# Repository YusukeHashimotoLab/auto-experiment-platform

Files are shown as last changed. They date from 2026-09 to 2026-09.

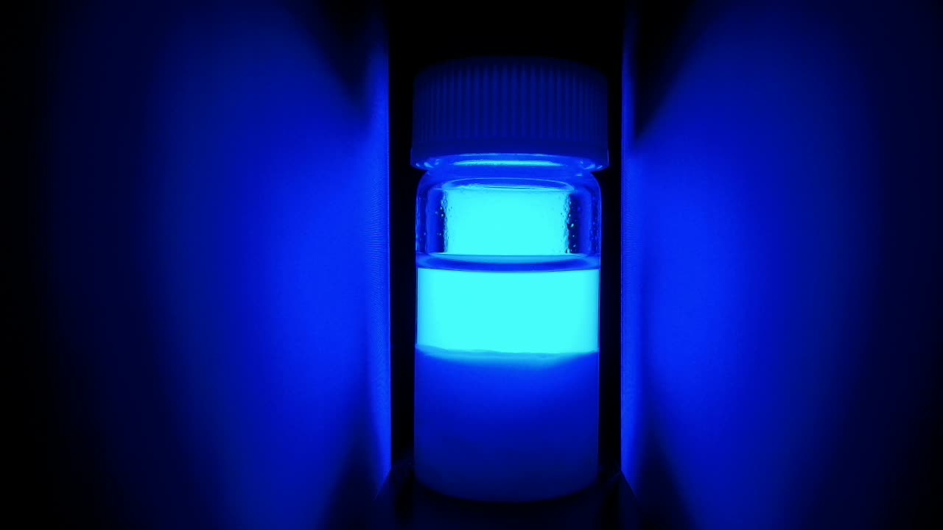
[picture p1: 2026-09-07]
src/imaging/examples/zif8_vial_5s/shot_blue.jpg

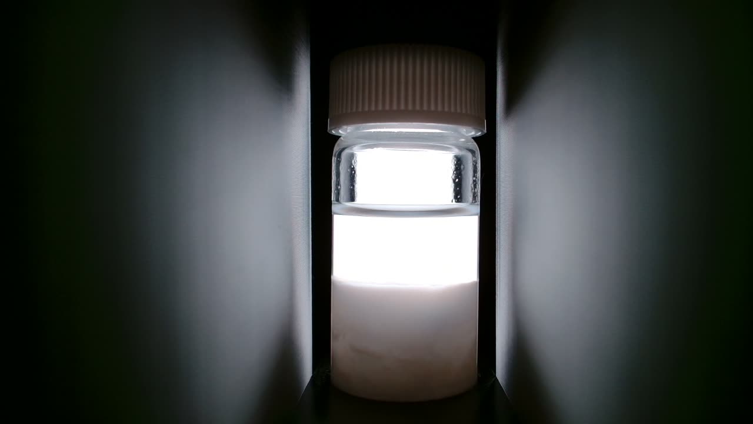
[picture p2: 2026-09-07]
src/imaging/examples/zif8_vial_5s/ref_white.jpg

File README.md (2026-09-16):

# SAIGEN

**SAIGEN** — **S**tandardized **A**utomation **I**nfrastructure for **G**eneralizable
**E**xperiment reproductio**N** (also *saigen*, 再現, Japanese for "reproduction").

A simple, easy-to-introduce, open-source platform for automated materials-synthesis
experiments, focusing on **reliable automation and quantitative process recording**
rather than full autonomy.

Repository: https://github.com/YusukeHashimotoLab/saigen

A manuscript describing the platform and its ZIF-8 demonstration is in preparation
(working title: *Quantitative control and improved reproducibility of materials
synthesis processes using an automated experimentation platform*). It is referred to
as "the paper" throughout this repository; a citation will be added here once it is
available.
<!-- TODO: add the citation / DOI when the manuscript is published, and add a
     preferred-citation block to CITATION.cff. -->

The platform combines commercially available instruments (robot arms, electric
pipettes, web cameras, an electronic balance) with 3D-printed fixtures, and operates
them with control code generated by an AI agent based on a large language model (LLM).
As a demonstration, ZIF-8 (a metal–organic framework) was synthesized with a
two-solution mixing system, and the dependence of its particle size distribution on
the solution dispensing speed was quantified and reproduced.

**Video:** the two-solution mixing system built on this platform, in operation:
https://youtu.be/5X2-4LuQfns

## Repository layout

| Path | Contents |
|---|---|
| `src/agent/` | AI agent that generates JSON experimental flows from natural language (Gemini API or any OpenAI-compatible endpoint) and the preset flows |
| `src/devices/` | Control drivers for each instrument (robot arm, electric pipette, hot-plate stirrer, electronic balance, webcam) and the safety wrapper the flows run through |
| `src/flow/` | Schema, validator, executor and command-line runner for the JSON experimental flow format |
| `src/gui/` | Browser-based GUI for parameter input and flow confirmation |
| `src/voice/` | Voice input (whisper-large-v3-turbo) |
| `src/monitoring/` | IoT sensor logging (Raspberry Pi + Environment Sensor HAT) and process cameras |
| `src/imaging/` | Appearance-imaging system: NEEWER RGB62 light + Logitech C920n camera control, white/red/green/blue capture sequence, cropped-image comparison and depth-direction transmitted-light profiles (paper Figure 6) |
| `detection/` | Object detection based on YOLOv8 — **kept separate for licensing reasons, see below** |
| `cad/` | CAD design bank of 3D-printable experimental components (STL + editable Fusion 360 sources) |
| `docs/` | Bill of materials, setup guide, experimental-flow format reference, spreadsheet-input guide, guide to adding an instrument |
| `examples/zif8/` | Sample experimental flows of the ZIF-8 demonstration (JSON equivalents of the spreadsheet sequence) and monitoring CSV templates |
| `examples/dispensing_stability/` | Measured data of the 100-shot dispensing-repeatability test and the script that recorded it |

## Getting started

1. See [`docs/bom.md`](docs/bom.md) for the full list of hardware used.
2. Print the fixtures in `cad/` (STL files; the Fusion 360 sources are included for
   modification — see [`cad/README.md`](cad/README.md)).
3. Follow [`docs/setup.md`](docs/setup.md) to connect the instruments to the control PC.
4. Copy `config.example.yaml` to `config.yaml` and set the COM ports and workspace
   limits of your own cell; copy `.env.example` to `.env` and set your API keys.
   **Never commit `.env` or `config.yaml`.**
5. Install the Python dependencies: `pip install -r requirements.txt`
   (module-specific notes, e.g. for the imaging system, are in each `src/<module>/README.md`).
   Check the installation with `pytest tests/` — the suite needs no hardware.
6. Dry-run a flow without hardware, then run it for real. The ZIF-8 examples are the
   JSON equivalents of the spreadsheet sequence in step 7, which is the path the
   paper's batches were actually run with:

   ```bash
   python -m src.flow.run_flow examples/zif8/zif8_two_solution_mixing_speed5.json --mock
   python -m src.flow.run_flow examples/zif8/zif8_two_solution_mixing_speed5.json
   ```

   Every move is checked against the `workspace` limits in `config.yaml` before the
   robot is commanded — in `--mock` mode too. Ctrl+C is an emergency stop: the arm
   halts where it is rather than driving home. Each run leaves
   `logs/<date>/<flow>_<time>/` with `run.log`, `measurements.csv`, `summary.md`,
   `metadata.json` and a copy of the flow; add `--no-record` to skip the sensor-CSV
   and video recording that real runs start by default.

7. Or set the parameters in a spreadsheet — **this is the path used for the paper's
   ZIF-8 experiments**: the two-solution mixing experiment (shown in the
   [video](https://youtu.be/5X2-4LuQfns) above) runs from a
   `parameter,value,note` CSV, with no JSON at all:

   ```bash
   cp src/flow/csv_runner/control.example.csv src/flow/csv_runner/control.csv
   python -m src.flow.csv_runner.run_csv --mock   # then without --mock for a real run
   ```

   The sheet is range-checked before any device is opened, the generated steps go
   through the same schema and workspace validator as a JSON flow, and the run leaves
   the same log folder; see [`docs/csv-runner.md`](docs/csv-runner.md).

8. Or use the GUI, where flows can also be generated from natural language or voice
   (the reported ZIF-8 batches did not use this path):

   ```bash
   streamlit run src/gui/app.py
   ```

   Ports come from `config.yaml` and stay editable in the sidebar; the flow is
   validated against the same schema before any device is opened, *Mock* runs it
   end to end without hardware, *Stop* aborts through the same emergency-stop path
   as Ctrl+C, and the run leaves the same `logs/<date>/…` folder as the CLI.

## Using SAIGEN with an AI coding agent

The intended way to adopt SAIGEN is to clone (or download) the repository, open it
in an AI coding agent such as Claude Code, Codex or Cursor, and let the agent adapt
it to your hardware in conversation. [`CLAUDE.md`](CLAUDE.md) (identical to
[`AGENTS.md`](AGENTS.md)) tells the agent how the repository is organised, how to
verify changes without hardware, and what it must not do on its own — in particular,
it must never start a real run or loosen the workspace limits without you asking.
A first message that works well:

> Read CLAUDE.md, then help me adapt this platform to my hardware: one Dobot Magician
> on COM3 with a Picus 2 pipette on COM4, a BCE8221 balance on COM8 and no second robot.
> Validate and mock-run an example flow when you are done.

Everything the agent does is also available by hand through the steps above.

The flow format is described in [`docs/experimental-flow.md`](docs/experimental-flow.md),
the spreadsheet input in [`docs/csv-runner.md`](docs/csv-runner.md), and adding an
instrument to the platform in [`docs/adding-an-instrument.md`](docs/adding-an-instrument.md); the ZIF-8 flows —
JSON equivalents of the spreadsheet sequence the paper's batches were run with — are in
[`examples/zif8/`](examples/zif8/).

## Licensing

- **Code** (`src/`, `examples/`): MIT License — see [`LICENSE`](LICENSE). Third-party components are listed in [`THIRD_PARTY_NOTICES.md`](THIRD_PARTY_NOTICES.md).
  The robot-arm driver uses [pydobot](https://github.com/luismesas/pydobot)
  (Copyright 2017 Luis Mesas, MIT License) with a small patch in
  `src/devices/dobot/pydobot_patch.py`. The vendor SDK (DobotDll) is **not** used and
  is not included in this repository.
- **CAD models and documentation** (`cad/`, `docs/`): Creative Commons Attribution 4.0
  (CC BY 4.0, https://creativecommons.org/licenses/by/4.0/); the CAD-specific notes are in
  [`cad/README.md`](cad/README.md).
- **Object detection** (`detection/`): depends on [Ultralytics YOLOv8](https://github.com/ultralytics/ultralytics),
  which is licensed under **AGPL-3.0**. This module is therefore isolated from the
  MIT-licensed code and is distributed under AGPL-3.0. The rest of the platform runs
  without it (object detection is an optional monitoring feature).

The fine-tuned YOLOv8 weights and the training images are **not** included in this
repository. `detection/README.md` describes how to fine-tune your own model for your
setup.

## Citing

If you use SAIGEN, please cite the software using the metadata in
[`CITATION.cff`](CITATION.cff) (GitHub's "Cite this repository" button). A paper
citation will be added once the manuscript above is published.

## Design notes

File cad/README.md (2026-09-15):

# CAD design bank

3D-printable experimental components. All models were designed with Autodesk
Fusion 360 and printed on a Bambu Lab X1E.

**License: CC BY 4.0** (https://creativecommons.org/licenses/by/4.0/).
You may share and adapt these models, including commercially, with attribution
to the designers listed below and to the paper (see repository README).

## Designers

| Designer | Affiliation | Contact | Components |
|---|---|---|---|
| Takaya Muramoto (村元貴哉) | Graduate School of Engineering, Tohoku University | muramoto.takaya.s1@dc.tohoku.ac.jp | `pipette-holder/` |
| Yusuke Hashimoto (橋本佑介) | Frontier Research Institute for Interdisciplinary Sciences, Tohoku University | yusuke.hashimoto.b8@tohoku.ac.jp | `robot-arm-holder/`, `balance-cover/` (cover and adapters), `imaging-stand/` |

Questions about a model, or corrections to it, go to its designer.

## Components

Every part is provided as a binary STL (millimetres, exported from Fusion 360),
ready to slice, and — where available — as the editable Fusion 360 source.
Bounding boxes are taken from the meshes.

| Directory | Component | Print file | Editable source | Size X × Y × Z (mm) | Designer |
|---|---|---|---|---|---|
| `robot-arm-holder/` | Pedestal that fixes the robot arm (Dobot Magician) to the bench and raises it by 210 mm | `dobot_magician_holder_210mm.stl` | `dobot_magician_holder_210mm.f3d` | 150 × 150 × 211 | Y. Hashimoto |
| `pipette-holder/` | Holder fixing the electric pipette (Sartorius Picus 2) to the robot arm tip | `picus2_holder.stl` | `picus2_holder.f3d` | 32 × 67 × 135 | T. Muramoto |
| `balance-cover/` | Liquid-splash cover for the electronic balance (Sartorius BCE822i), with windshield; its top plate has a Ø82 mm opening for the vessel adapters below | `balance_cover_bce822i.stl` | `balance_cover_bce822i.f3d` | 275 × 240 × 109 | Y. Hashimoto |
| `balance-cover/adapters/` | Vessel adapter for the cover opening: ring for a No. 4 screw-cap vial (13.5 mL; e.g. AS ONE 9-852-06), Ø25 mm chamfered hole | `vial_adapter_screw_no4.stl` | `vial_adapter_screw_no4.f3d` | 92 × 92 × 10 | Y. Hashimoto |
| `balance-cover/adapters/` | Vessel adapter for the cover opening: sleeve for a 50 mL centrifuge tube, Ø30 mm bore | `tube_adapter_centrifuge_50ml.stl` | `tube_adapter_centrifuge_50ml.f3d` | 90 × 92 × 70 | Y. Hashimoto |
| `imaging-stand/` | Holding stand for the appearance-imaging system (light, sample, camera) | `imaging_stand_assembly.stl` (one mesh of the whole assembly) | `imaging_stand_assembly.f3z` (Fusion archive: stand, assembly and light fixture designs) | 204 × 90 × 100 | Y. Hashimoto |
| `imaging-stand/` | Light shield placed over the imaging stand | `imaging_stand_light_shield.stl` | `imaging_stand_light_shield.f3d` | 250 × 120 × 120 | Y. Hashimoto |

Notes:

- The two vessel adapters share the same seat: a Ø92 mm flange resting on the top
  plate of the balance cover and a Ø81 mm spigot that drops into its Ø82 mm opening,
  so they are interchangeable without modifying the cover. Print one per vessel
  type you use.
- `.f3d` is a single Fusion 360 design; `.f3z` is a Fusion 360 archive that bundles
  an assembly with the designs it references. Open either with *File → Open* in
  Fusion 360 (upload to your project).
- The meshes were checked to be closed (no open edges). `dobot_magician_holder_210mm.stl`
  is exported from a multi-body design, so a few internal faces are shared between
  touching bodies; slicers merge these, but re-export from the `.f3d` if your tool
  complains about non-manifold edges.
- The original file names were Japanese; they were renamed to ASCII for portability.
  Same geometry.
- STEP exports are not included; export them from the `.f3d` / `.f3z` sources if you
  need a neutral format.

<!-- TODO: add recommended print settings (material, layer height, infill) per component. -->

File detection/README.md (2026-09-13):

# Object detection module (YOLOv8)

Optional monitoring feature: detects the electric pipettes (mounted on the robot arms)
in the recorded overhead-camera video, as an offline analysis of the experimental state.

## License notice

This module depends on [Ultralytics YOLOv8](https://github.com/ultralytics/ultralytics),
which is licensed under **AGPL-3.0**. To keep the rest of the platform under the MIT
license, this module is isolated here and is distributed under **AGPL-3.0**. The
platform runs without this module; only the camera-based object detection is disabled.

The full license text is in [`LICENSE`](LICENSE) in this directory (a verbatim copy of
<https://www.gnu.org/licenses/agpl-3.0.txt>) and applies to **everything under
`detection/` only**. The rest of this repository is MIT (code, see the top-level
[`LICENSE`](../LICENSE)) and CC BY 4.0 (documentation and CAD), and imports nothing
from `ultralytics` — verify with:

```bash
grep -rn "ultralytics" src examples   # no matches
```

Because `ultralytics` is imported only by the files in this directory, the AGPL's
copyleft does not reach the rest of the platform. If you redistribute or offer network
access to a modified version of *this module*, AGPL-3.0 §13 requires you to offer the
corresponding source. See also [`../THIRD_PARTY_NOTICES.md`](../THIRD_PARTY_NOTICES.md).

## Purpose and scope

The paper's overhead camera (Logitech C920n) records the automated experiment, and a
YOLOv8 model fine-tuned on images of the electric pipettes detects them in the
recorded frames. In the current setup this detection is run **offline, after the
experiment**, on the saved video file — it is a post-hoc analysis step, not a
component of the live experiment log produced by `src/monitoring/`. `infer_video.py`
writes a per-frame CSV of detections that can be joined to the sensor/process log by
frame index or timestamp, but no such join is performed automatically.

## Dataset

The published model was fine-tuned on 59 still images of the experimental setup,
each annotated with a single bounding box for the class `electric_pipette`
(single-class dataset, 59 boxes total):

- Images: photographed with an iPhone, 4284 px wide, converted from HEIC to JPG.
- Annotation tool: [labelme](https://github.com/wkentaro/labelme) rectangles, one JSON
  file per image (`{stem}.json` next to `{stem}.jpg`).
- Conversion: `prepare_dataset.py` reads the labelme JSON files, converts the
  rectangles to YOLO's normalized `class x_center y_center width height` format, and
  copies the images into a train/val split.
- Split: 80 / 20, seed 42 -> **47 train / 12 val** images.

## Fine-tuning configuration

The distributed configuration (`train.py` defaults) matches the run actually used to
produce the published weights (referred to as `electric_pipette2` in the original
working repository):

| Parameter | Value |
|---|---|
| Base model | `yolov8n.pt` (COCO-pretrained, no transfer from an earlier custom run) |
| Image size | 1280 |
| Batch size | 4 |
| Epochs | 100 (ran to completion) |
| Patience (early stopping) | 50 |
| Optimizer | auto (Ultralytics' automatic optimizer/LR selection) |
| LR schedule | cosine (`cos_lr=True`) |
| Mosaic augmentation | enabled, disabled for the final 10 epochs (`close_mosaic=10`) |
| Device | Apple Silicon MPS |
| Seed | 0, deterministic |

Augmentation defaults that matter for this dataset (Ultralytics defaults, unchanged):
`mosaic=1.0`, `fliplr=0.5`, `hsv_h=0.015`, `hsv_s=0.7`, `hsv_v=0.4`, `scale=0.5`,
`translate=0.1`.

An earlier run (`electric_pipette`, imgsz 640, batch 8, patience 20) was stopped early
after 31 epochs and is superseded by the configuration above; it is not otherwise
documented here.

## Validation metrics

Best epoch on the validation split (epoch 85 of 100):

| Metric | Value |
|---|---|
| Precision | 1.000 |
| Recall | 0.970 |
| mAP50 | 0.995 |
| mAP50-95 | 0.739 |

## Reproduce

1. Install dependencies: `pip install -r detection/requirements.txt`
2. Place your own annotated images in `detection/data/` (labelme JSON files) and
   `detection/data/images_jpg/` (the corresponding JPGs), following the layout
   described above.
3. Build the YOLO-format dataset:
   ```
   python prepare_dataset.py --data-dir data --out dataset --train-ratio 0.8 --seed 42
   ```
4. Copy `data.example.yaml` to `data.yaml` (adjust `path` if needed), then train:
   ```
   python train.py --data data.yaml --model yolov8n.pt --epochs 100 --imgsz 1280 \
       --batch 4 --patience 50 --device auto --name electric_pipette --project runs
   ```
5. Run offline inference on a recorded experiment video:
   ```
   python infer_video.py --model runs/electric_pipette/weights/best.pt \
       --source video.mp4 --conf 0.25 --imgsz 960 --device auto
   ```
   This saves the annotated video/frames plus `detections.csv`
   (`frame, n_detections, max_conf`) under `runs/video_result/`.

`--device auto` lets Ultralytics pick the best available backend; pass `mps`, `cuda`,
`cuda:0`, or `cpu` explicitly if you need to force one.

## Weights and training data

The fine-tuned weights and training images used in the paper are **not** distributed
(they contain laboratory-specific scenes). `weights/` and `dataset/` are gitignored.
To obtain a model:

1. Capture images of your own setup with the overhead camera.
2. Annotate the objects of interest with labelme (or another tool, converting to the
   labelme JSON schema `prepare_dataset.py` expects).
3. Fine-tune a YOLOv8 model on the annotated images using the steps above.
4. Place the resulting weights in `weights/` (gitignored).

If you need the exact weights used in the paper for comparison purposes, contact the
authors.

## Not included: additional video frames

The lab's working copy also holds 20 unannotated frames extracted from an
experiment video (`data/video_frames/`), collected for a planned but never-run third
training pass that would have added video-derived frames to the still-image dataset.
These frames are **not** part of the published model's training set described above
and are not included in this repository.

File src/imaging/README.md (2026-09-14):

# Imaging module

Appearance-imaging system for SAIGEN, the automated experimentation platform (see the
[repository README](../../README.md) for the manuscript in preparation that this
module's results belong to). It backlights a sample vial with an RGB light,
photographs it under white, red, green and blue illumination with a fixed
camera, and turns those photographs into cropped side-by-side comparisons and
depth-resolved transmitted-light intensity profiles — the material behind the
paper's "Imaging system for appearance evaluation" section and Figure 6.

## System configuration

### Hardware

| Component | Model | Interface | Notes |
|---|---|---|---|
| Light | NEEWER RGB62 | Bluetooth LE | White (CCT) and single-colour (HSI) modes; controlled by [`neewer_light.py`](neewer_light.py) |
| Camera | Logitech C920n (HD Pro Webcam C920) | USB | Video + control abstracted by [`hw.py`](hw.py) |
| Holding stand | 3D-printed | — | Fixes the relative positions of light, vial and camera; STL and Fusion 360 sources in [`cad/imaging-stand/`](../../cad/imaging-stand/), together with a light shield placed over the stand |
| Control PC | — | — | Runs `camera_server.py`, `acquire.py`, `make_panel.py` |

See [`docs/bom.md`](../../docs/bom.md) for the full platform bill of materials.

### Geometry

The stand holds the light, sample vial and camera on one fixed optical axis so
every photograph is a backlit transmission image of the same region:

```
 NEEWER RGB62        sample vial            Logitech C920n
 (backlight)  -->  (screw-top vial,   -->  (USB, fixed focus
                    suspension below         and exposure)
                    clear supernatant)
   |____________________|____________________|
        all three fixed by the stand (cad/imaging-stand/)
```

### Software-fixed conditions

Imaging conditions are fixed in software rather than by hand, so repeated
photographs are comparable:

- **Camera** — [`config/camera_reference.json`](config/camera_reference.json)
  is the single source of truth: exposure 20 (macOS `exposure-time-abs`
  units; logged Windows equivalent `-9`), gain 0, focus 180, white balance
  4600 K manual. It stores this once per platform (macOS `uvc-util` control
  names under `"reference"`, Windows logical names under `"win32"`), applied
  through `hw.py`'s logical control names; `camera_server.py`'s `/api/health`
  and the acquisition scripts check the live camera against it.
- **Light** — [`config/light_reference.json`](config/light_reference.json)
  documents the illumination conditions used by `acquire.py`: a white CCT
  shot at 5600 K (used only for detecting the vial geometry; its brightness
  is auto-swept unless fixed with `--white-intensity`), and three HSI
  (single-colour) shots at hue 0° / 120° / 240° (red / green / blue), each at
  1 % intensity. This file is not read by any module at run time — it is a
  human-readable record of constants that are hard-coded in `acquire.py`.

**Two hard rules, both established by measurement on the C920:**

1. **White balance must stay manual at 4600 K. Never switch it back to
   auto.** The C920 has slow, hidden internal white-balance state; every time
   it is switched between auto and manual it settles into a different,
   non-reproducible colour state. Only an uninterrupted manual 4600 K holds a
   consistent colour balance.
2. **Changing exposure while the camera server's stream is running has no
   effect on the frames it serves.** The control write succeeds and reads
   back correctly, but the live MJPEG stream keeps using the exposure that
   was in effect when it started. To change exposure: set the new value,
   then restart `camera_server.py`. Adjusting brightness *during* a
   measurement should be done on the light, not the camera.

The three illumination wavelengths (625 / 525 / 465 nm) are the LED's
**nominal** values, not independently measured (±10-15 nm uncertainty); this
does not affect relative or time-series comparisons. Each single-colour LED
saturates its own dominant camera channel (red→R, green→G, blue→B) even at
1 % intensity, so photometry is always done on the **secondary** channel
(red→G, green→B, blue→G) — see `acquire.py`'s `COLORS` table and
`od_profile()`.

## Module map

| File | Role |
|---|---|
| [`paths.py`](paths.py) | Shared directory layout (`IMAGING_DATA_DIR`, `config/`, `examples/`) and `uvc-util` path resolution |
| [`hw.py`](hw.py) | Platform abstraction for the camera (macOS: ffmpeg + uvc-util; Windows: OpenCV/DirectShow) and the cross-platform measurement file lock |
| [`neewer_light.py`](neewer_light.py) | BLE control of the NEEWER RGB62 (CCT and HSI modes; macOS CoreBluetooth / Windows WinRT+bleak backends) |
| [`capture.py`](capture.py) | Thin HTTP client used by `acquire.py` to trigger captures and read/write camera controls through `camera_server.py` |
| [`camera_server.py`](camera_server.py) + [`static/`](static/) | Local web server (port 8799): live preview, camera/light controls, spot-measurement launcher, analysis viewer, and the HTML/JS front end |
| [`acquire.py`](acquire.py) | Capture sequence (white → red → green → blue) and the optical-density analysis (`od_profile`, sediment-front detection, figure generation) |
| [`geometry.py`](geometry.py) | Vial geometry detection from a white backlit photo (meniscus, cap, body, liquid bottom) |
| [`make_panel.py`](make_panel.py) | Publication panel figure: four cropped photographs plus the depth-resolved transmittance/OD curve |
| [`config/`](config/) | `camera_reference.json` (single source of truth for camera settings), `camera_local.example.json` (per-PC camera selection template), `light_reference.json` (documentation of the light constants) |
| [`examples/`](examples/) | One complete example run (see below) |

## Installation

From the repository root:

```bash
pip install -r requirements.txt
```

Platform-specific notes for this module:

- **macOS** — video comes from `ffmpeg` (AVFoundation) and camera control
  from `uvc-util`; both are external executables, **not bundled** here.
  Install `ffmpeg` with `brew install ffmpeg`; build `uvc-util` from
  [github.com/jtfrey/uvc-util](https://github.com/jtfrey/uvc-util) and put it
  on `PATH`, or point the `UVC_UTIL` environment variable at the binary (see
  `paths.uvc_util_path()`). The light backend uses PyObjC (`pyobjc-framework-CoreBluetooth`,
  `pyobjc-framework-libdispatch`), which `requirements.txt` installs on macOS only.
- **Windows** — video and camera control both go through OpenCV's DirectShow
  backend, which is why `requirements.txt` pins `opencv-python==4.12.0.88`:
  4.13+ (including 5.0) breaks get/set of `CAP_PROP_WHITE_BALANCE_BLUE_U` on
  the C920, the property used to hold the required manual 4600 K white
  balance. `pygrabber` (already listed) enumerates DirectShow devices and
  pulls in `comtypes` automatically. The light backend prefers piggybacking
  on an already-connected device via the `winrt` packages (not pinned) and
  falls back automatically to scanning with `bleak` (already listed) if they
  are absent. On a PC with more than one webcam, copy
  `config/camera_local.example.json` to `config/camera_local.json`
  (git-ignored) and set `win32_device_name`/`win32_device_path` to pick the
  C920 unambiguously — `hw.py` refuses to start on zero or multiple matches.
- **The light** must be powered on before starting `camera_server.py`. On
  macOS, `neewer_light.py` piggybacks onto an existing BLE connection rather
  than opening its own, so it can share a connection already held by the
  NEEWER Control Center app instead of competing with it.
- **`IMAGING_DATA_DIR`** (environment variable) sets where captured photos
  and analysis output go. Default: `imaging_data/` at the repository root
  (`photos/` and `analysis/` subdirectories; see `paths.py`). The location is
  anchored to the module file, not to the current directory, so the camera
  server and a hand-run `acquire.py` always write to the same place.

## Usage

### 1. Start the camera server

```bash
python camera_server.py
```

Open `http://localhost:8799`. The page has five tabs:

- **Camera** — sliders for exposure, gain, focus and white balance (Kelvin),
  auto-exposure/auto-focus/auto-white-balance toggles, and a manual
  **Capture** button; a warning banner reminds you to keep white balance
  manual at 4600 K, and flags that exposure changes need a server restart to
  reach the live preview.
- **Light** — On/Off, and either White (CCT: brightness + colour temperature)
  or Monochrome (HSI: hue + saturation + brightness, with quick Red 625 /
  Green 525 / Blue 465 buttons) control.
- **Measure** — a named spot measurement: Full (white+RGB) or White-only
  mode, folder and sample name, and toggles for a locked frame, fixed
  monochromatic LED intensity, or fixed white LED intensity (white-only
  mode). This is the UI front end for `acquire.py`, run as a subprocess and
  polled via `/api/spectral/status`.
- **Analysis** — a Refresh button and the most recent run's `spectral.png`.
- **Conditions** — one-shot frame (geometry) calibration, and named presets
  that save/apply/verify a full camera+light+geometry configuration.

### 2. Apply and verify the reference camera settings

Set the camera to the values in `config/camera_reference.json` (exposure 20 /
gain 0 / focus 180 / white balance manual 4600 K) using the Camera tab or the
`/api/control` endpoint, then confirm with:

```bash
curl http://localhost:8799/api/health
```

`matches_reference` should be `true`; `mismatches` lists any control that
differs from `camera_reference.json`, and `stream_settings_stale` flags the
"exposure changed but the stream didn't update" condition described above.

### 3. Acquire a run

```bash
python acquire.py --folder <experiment> --name <sample>
```

This drives the light through white → red → green → blue, capturing one
photo per step through the running `camera_server.py`, and writes the run to
`<IMAGING_DATA_DIR>/photos/<experiment>/<sample>/`. Useful options (see
`python acquire.py --help` for the full list):

| Option | Effect |
|---|---|
| `--mode {full,white}` | `full` (default): white + red/green/blue, ~3-wavelength OD. `white`: a single white shot only, giving per-camera-channel (R/G/B) OD — quicker, but only valid for named runs |
| `--white-intensity PCT` | Fix the white-shot LED intensity (white-only mode only) so multiple samples are photographed under identical illumination, for photo comparison or absolute-transmittance comparison |
| `--fixed-intensity` | Disable automatic monochromatic-LED intensity adjustment and hold it at `--intensity` (for cross-sample absolute comparison) |
| `--calibrate` | Detect the vial geometry once from a white reference and save it as a locked frame |
| `--locked` | Skip per-run geometry auto-detection and reuse the locked frame (for comparing swapped-in samples without shifts in field of view) |
| `--intensity`, `--restore` | Initial monochromatic LED intensity (default 1 %) and the light state to leave the light in when done (default: off) |

### 4. Run directory format

Each run directory contains:

| File | Contents |
|---|---|
| `ref_white.jpg` | White-light reference photo (geometry detection; also the photometry image itself in white-only mode) |
| `shot_red.jpg`, `shot_green.jpg`, `shot_blue.jpg` | Monochromatic captures (full mode only) |
| `profiles.csv` | Per-row optical density, one column per wavelength/channel (`od_625`/`od_525`/`od_465` in full mode, `od_R`/`od_G`/`od_B` in white-only mode) |
| `spectral.png` | OD-vs-depth figure generated by `acquire.py` at capture time |
| `summary.json` | Geometry (`meniscus_y`, `liquid_bottom_y`, `body_x0`/`x1`, `fill_fraction`), per-wavelength intensity/channel/warning, `sediment_front_y`, `white_balance_fixed`, and measured headspace brightness used to cross-check actual light intensity |

### 5. Make the publication panel

```bash
python make_panel.py examples/zif8_vial_5s --out panels
```

Outputs `<run_dir name>_panel.png` (300 dpi), `_panel.pdf`, and a draft
`_caption.md`, all under `--out` (default `./panels`) — `make_panel.py` never
writes into the run directory itself. Options (`python make_panel.py --help`):

| Option | Effect |
|---|---|
| `--y {transmittance,od}` | Right-panel x-axis: transmittance `T = 10^-OD` (default) or OD directly |
| `--with-white` | Also draw the white (G-channel) curve in the depth panel; omitted by default |
| `--mm-per-px MM` | Show the depth axis in millimetres (5 mm steps) instead of pixel rows |

The panel shows four cropped photographs (white, 625, 525, 465 nm, cap bottom
to vial bottom, all cropped to the same rectangle) beside a depth-resolved
transmittance/OD curve that shares the same vertical (pixel-row) scale as the
photographs, so visual features in the photos line up with inflections in the
curve. The white photograph is not plotted as a curve by default: its green
channel is saturated over a clear supernatant (the sensor clips before the
signal can be used quantitatively), so it is shown only as a visual
reference; `--with-white` draws it anyway. The saturated-row-fraction table
for all four channels is always printed to stdout regardless of that flag.

## Correspondence with paper Figure 6

| Figure 6 panel | Produced by |
|---|---|
| (a) appearance of the imaging system | The stand ([`cad/imaging-stand/`](../../cad/imaging-stand/)) and camera/light hardware described in [System configuration](#system-configuration) above |
| (b) a photograph taken with it | `examples/zif8_vial_5s/ref_white.jpg`, captured by `camera_server.py` via `acquire.py` |
| (c) sample images under white/red/green/blue illumination | The four cropped photo columns produced by `make_panel.py` from that same run |
| (d) depth profile of the transmitted-light intensity | The depth-resolved transmittance/OD curve in `make_panel.py`, computed from `profiles.csv` (written by `acquire.py`'s `od_profile()`) |

One example run is included, [`examples/zif8_vial_5s/`](examples/zif8_vial_5s/)
— the run behind those Figure 6 panels. It is a ZIF-8 suspension (white
sediment below a clear supernatant) synthesised by the platform in a
screw-top vial without stirring, with the second precursor solution
("solution 2") dispensed over 5 s, and photographed on 2026-07-14 at 13:25,
twelve days after synthesis.

It is included as a **worked example of the pipeline, not as a validated
measurement**, and it is not a dispensing-time comparison: it is a single
run at a single dispensing time. Its white reference and its 465 nm channel
are both sensor-clipped over the clear supernatant, and it predates the
reference camera exposure, so absolute transmittance is not comparable
across runs. [`examples/README.md`](examples/README.md) lists these caveats
in full — read it before reusing the numbers.

Figure 8 of the paper (nine vials, three per dispensing time) was **not**
taken with this imaging stand and is not reproduced by anything in this
directory.

## Analysis method

`acquire.py`'s `od_profile()` computes, for each wavelength/channel, a
depth-resolved optical density `OD(y) = -log10(I(y)/I0)`:

- Pixel values come from the secondary colour channel, averaged over the
  inner 60 % of the vial body's columns (avoiding light piped along the
  glass wall), then sRGB-linearised (inverse gamma) before any arithmetic.
- `I0` is the peak transmitted-light level just below the meniscus (past the
  refractive dip the curved liquid surface produces).
- A pedestal (lens flare + dark current) is normally estimated from the dark
  region above the cap; if attenuation is deep enough that the signal pins to
  stray light instead of continuing to fall, a flat low-value window further
  down is used as the floor instead and the curve is truncated there (a
  lower bound on OD only).
- The sedimentation front is the shallowest depth where the 625 nm OD rises
  above a fixed threshold for a sustained run of rows.

## Limitations / notes

- The 625 / 525 / 465 nm wavelengths are the LED's nominal values, not
  independently measured (±10-15 nm); verify with a spectrometer or
  diffraction grating before using them quantitatively rather than for
  relative/time-series comparison.
- The geometry detector (`geometry.py`) and the fixed-frame comparison mode
  assume a single vial on a fixed optical axis; it is not a general-purpose
  multi-sample imaging pipeline.
- Camera behaviour (the white-balance hidden state, the live-exposure
  pitfall, per-channel saturation under single-colour LEDs) is specific to
  the Logitech C920/C920n and was established by measurement on that
  camera; a different webcam model may not share these quirks — or may have
  different ones.
- This is a photographic transmission measurement, not a calibrated
  spectrophotometer: optical density values are useful for relative and
  time-series comparison under matched conditions, not as absolute
  extinction coefficients.

## License

MIT, as the rest of `src/` — see [`LICENSE`](../../LICENSE).

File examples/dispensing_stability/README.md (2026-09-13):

# Dispensing stability (100 repeated 3 mL injections)

Raw data and the historical control script for the dispensing-stability
measurement reported in the paper (§3.3 Methods, §4.1 Results).

## What was measured

Ion-exchanged water was aspirated and dispensed **100 times** at the **same
nominal volume of 3 mL**, by one robot arm carrying a Sartorius Picus 2
electronic pipette. After each injection the receiving vessel was weighed on
the electronic balance and the **difference from the previous reading** was
recorded as the dispensed mass. At room temperature the density of water is
close to 1 g/mL, so the mass in grams is read directly as the delivered volume
in millilitres.

| Item | Value |
|---|---|
| Liquid | Ion-exchanged water |
| Nominal volume per injection | 3 mL |
| Repetitions | n = 100 |
| Pipette | Sartorius Picus 2 (electronic), on a Dobot Magician arm |
| Aspiration speed step | 9 |
| Dispensing speed step | **9** (`dispensation_speed_1 = 9` in `control_250328.py`) |
| Wait between aspirate and dispense | 1 s (`wait_seconds`) |
| Balance | Sartorius BCE822i, readability **0.01 g** |
| Date | 2025-03-28 |

At speed step 9 the driver's timing table
(`src/devices/picus2/picus2_controller.py`, 0.9 s per 10 mL) gives a nominal
dispensing time of **≈0.27 s for 3 mL (≈11 mL/s)**.

> The balance readability of 0.01 g is the floor on the measurement: the
> scatter reported below is only about twice the quantisation step of the
> instrument, so it is an upper bound on the true dispensing variability
> rather than a precise estimate of it.

## Files

| File | Contents |
|---|---|
| `weight.csv` | The raw data: header `weight` plus 100 balance differences in grams, verbatim as written by the script. |
| `control_250328.py` | The script that produced `weight.csv` on 2025-03-28, verbatim apart from an added provenance header and the redaction of the pipettes' Bluetooth addresses and serial numbers. It imports the lab-local modules `ika_control`, `material_injection` and `BCE8221`, which are **not** part of this repository, so it is **not runnable here** — it is kept for provenance. |
| `stats.py` | Recomputes the statistics below from `weight.csv` (standard library + NumPy only). |

## Statistics

Computed from `weight.csv` in this directory with `stats.py`:

```
$ python examples/dispensing_stability/stats.py
n    : 100
mean : 3.0102 g
SD   : 0.0222 g   (sample, ddof=1)
RSD  : 0.738 %  (100 * SD / mean)
min  : 2.93 g
max  : 3.09 g
```

| Quantity | Formula | Value |
|---|---|---|
| n | number of rows in `weight.csv` | 100 |
| Mean | *x̄* = (1/n) Σ *xᵢ* | 3.0102 g |
| Standard deviation (sample) | *s* = √( Σ(*xᵢ* − *x̄*)² / (n − 1) ) — i.e. `ddof=1` | 0.02220 g |
| Relative standard deviation | RSD = 100 · *s* / *x̄* | 0.738 % |
| Minimum | min *xᵢ* | 2.93 g |
| Maximum | max *xᵢ* | 3.09 g |

The *population* standard deviation (`ddof=0`) is 0.02209 g, i.e. an RSD of
0.734 %; the choice of `ddof` does not change the rounded values quoted in the
paper.

## Comparison with the paper

| Quantity | Paper (§3.3 / §4.1) | Recomputed here | Agrees? |
|---|---|---|---|
| n | 100 | 100 | yes |
| Mean | 3.010 g | 3.0102 g | yes |
| SD | 0.022 g | 0.02220 g | yes |
| RSD | 0.74 % | 0.738 % | yes (0.738 % rounds to 0.74 %) |

No mismatch was found: every number the paper quotes is reproduced by
`stats.py` from the CSV in this directory. The paper does not quote min/max;
those are given above for completeness.

Two details are *not* stated in the paper and are recorded here from the
script instead: the speed step used (9, both aspiration and dispensing) and the
1 s wait between aspiration and dispensing.

## Reproducing the numbers

```bash
python examples/dispensing_stability/stats.py
# or point it at your own file with the same one-column layout
python examples/dispensing_stability/stats.py path/to/your_weights.csv
```

Requires NumPy only (already in `requirements.txt`).

## Reproducing the measurement on this platform

`control_250328.py` cannot be run here. The equivalent measurement is expressed
as a JSON flow for `src/flow/` — a `tare_scale` / `aspirate` / `dispense` /
`measure_weight` cycle inside a loop — using the volume, speed and wait values
from the table above. See [`docs/experimental-flow.md`](../../docs/experimental-flow.md)
for the schema and [`examples/zif8/`](../zif8/) for a worked flow.

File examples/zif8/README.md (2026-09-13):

# ZIF-8 demonstration

Experimental flows for the two-solution mixing demonstration described in the paper:
ZIF-8 synthesis in which solution 2 is dispensed at three different **pipette speed
steps (1, 5 and 9)**, three trials per condition in alternating order.

The batches themselves were run from a spreadsheet — see
[`docs/csv-runner.md`](../../docs/csv-runner.md) and Provenance below. The JSON files
here express that same sequence for the JSON runner.

## Provenance — please read first

> **The paper's batches were run through the CSV runner, not through these JSON
> files.**
>
> The nine ZIF-8 batches reported in the paper were executed with the lab's
> spreadsheet runner — the internal `excel_runner/run_csv.py`, published here as
> [`src/flow/csv_runner/`](../../src/flow/csv_runner/) — in the version in force
> from 2026-07-02 onward (internal commit `4584333`, 2026-06-30). No
> LLM-generated JSON flow was executed for those runs. The operator typed the
> volumes, Z descents, angles and pipette speeds into a spreadsheet and the
> runner performed a fixed sequence.
>
> **The three JSON files in this directory are the equivalent flows for the JSON
> path.** They reproduce that fixed sequence step for step, so that the same
> experiment can be run through `src/flow/run_flow.py` or the GUI, and so that the
> sequence is readable without running anything. They are not the run records of
> the paper's experiments.
>
> Concretely, this means:
>
> - The **motion sequence** is the historical one, taken from the source of the
>   runner version above: descend onto the source vial → aspirate → rise → rotate
>   to the balance → descend → **tare with the tip already lowered** → dispense →
>   **read the mass before the tip rises** → rise → `go_home` (the home move also
>   undoes the rotation). Robot 1 completes its sequence, then Robot 2.
> - The **numeric values** — 5 mL per solution, 0.1 mm aspiration descent, 120 mm
>   dispensing descent, ±90° rotations, Robot 1 dispensing at speed 9, aspiration
>   at speed 1 for both robots — are those of the lab's committed control sheet at
>   that commit. They are **not necessarily the values of every batch**: the
>   dispensing speed of Robot 2 was varied over 1 / 5 / 9 across the nine batches,
>   which is what these three files differ in. The per-batch run records are not
>   published yet; when they are added they will replace the placeholder sensor
>   CSVs below.
> - Aspiration ran at **speed 1** in every batch: it was the code constant
>   `ASPIRATE_SPEED = 1`, not a spreadsheet cell. (A note in the lab's sheet
>   claimed aspiration was "always 5"; that note was stale and never affected the
>   runs.)
> - The **single `capture_and_save` at the end of each JSON file is an addition**
>   of this public example. The CSV sequence took no photograph; the public runner
>   offers it as the optional `capture_photo` parameter, off by default.
> - The **dispensing times quoted below are nominal**, computed from the Picus 2
>   speed table in the pipette manual, not measured on the instrument.
> - The **geometry is fixture-specific**. It is the geometry of the original
>   setup, but it has not been re-verified against it; measure your own flask and
>   vial positions before a real run.
> - The CSV files `sensor_session_sample.csv` and `sensor_session_sample_tags.csv`
>   are **column templates with fabricated values**, not measurements. See
>   [Monitoring sample files](#monitoring-sample-files-placeholders) below.
>
> Nothing in this directory should be cited as measured data.

## Files

The three flow files are identical except for the `speed` of the solution-2
`dispense` step. Solution 1 is always dispensed at speed 9 (nominal 0.45 s for
5 mL) and both solutions are aspirated at speed 1.

| File | Solution 2 `dispense.speed` | Nominal time for 5 mL | Nominal rate |
|---|---|---|---|
| `zif8_two_solution_mixing_speed1.json` | 1 | 5.1 s | 0.98 mL/s |
| `zif8_two_solution_mixing_speed5.json` | 5 | 1.45 s | 3.4 mL/s |
| `zif8_two_solution_mixing_speed9.json` | 9 | 0.45 s | 11.1 mL/s |

### Picus 2 speed steps → nominal time for 5 mL

The Picus 2 electronic pipette is set by a **speed step from 1 to 9**, not by a
time. The manual (p. 63) gives the seconds needed per 10 mL at each step; this
table is encoded in `calculate_operation_time()` in
[`src/devices/picus2/picus2_controller.py`](../../src/devices/picus2/picus2_controller.py).
Times for 5 mL are half of those values:

| Speed step | s per 10 mL (manual) | Nominal time for 5 mL | Nominal rate for 5 mL |
|---|---|---|---|
| 1 | 10.2 | 5.10 s | 0.98 mL/s |
| 2 | 7.4 | 3.70 s | 1.35 mL/s |
| 3 | 5.4 | 2.70 s | 1.85 mL/s |
| 4 | 3.8 | 1.90 s | 2.63 mL/s |
| 5 | 2.9 | 1.45 s | 3.45 mL/s |
| 6 | 2.2 | 1.10 s | 4.55 mL/s |
| 7 | 1.7 | 0.85 s | 5.88 mL/s |
| 8 | 1.3 | 0.65 s | 7.69 mL/s |
| 9 | 0.9 | 0.45 s | 11.11 mL/s |

These are **nominal** figures from the manual's table, linear in volume. They do
not include the pipette's own acceleration and settling, and they were not
measured on the instrument, so the actual dispensing time will differ. The
**speed step is the quantity that was actually set and is therefore the primary
fact**; the times are given only to make the conditions interpretable.

> Earlier drafts of this repository named the files `_5s`, `_2s` and `_0.5s` and
> described speed 5 as "~2.0 s". That was wrong: 2.0 s for 5 mL corresponds to
> speed 4 (1.9 s), not speed 5. The files have been renamed after the speed step
> they set, and the times recomputed from the table above.

## What the flow does

The same sequence as a CSV run, in the same order:

1. **Robot 1 / solution 1** (Zn(NO₃)₂·6H₂O + PEG in DMF): lower 0.1 mm onto the
   source vessel, aspirate 5 mL at speed 1, rise, rotate +90° over the vial on the
   balance, lower 120 mm into it.
2. Tare the balance at that lowered position, dispense 5 mL at speed 9, and read
   the balance **before** the tip rises (median of 3 readings — the mass of
   solution 1).
3. Raise the arm 120 mm and send Robot 1 home; the home move also undoes the
   rotation, so there is no separate rotate-back step.
4. **Robot 2 / solution 2** (2-methylimidazole + triethylamine in DMF): the same
   ten steps mirrored (rotation −90°), dispensing at the speed step under test.
5. Photograph the vial — **this last step only exists in these JSON examples**;
   the CSV runs that produced the paper's data ended after Robot 2 went home.

Reagent quantities, stirring conditions and the pre-mixing procedure are given in the
paper (Methods). Solution recipes are not encoded in the flow: the flow only moves,
aspirates, dispenses, weighs and photographs.

## Adapting to your setup

- `move_z` distances (−0.1 / +0.1 mm at the source vessel, −120 / +120 mm into the
  vial on the balance) and the ±90° `rotate_relative` angles are specific to the
  fixture geometry of the original setup — see Provenance above — and were not
  re-verified against it.
  Measure your own flask and vial positions relative to each robot's home position and
  edit these values. Use `--mock` first, then the "position check" presets in
  `src/agent/presets/` (`wdc_2_dispense_robot1.json`, `wdc_3_dispense_robot2.json`)
  with the pipette steps removed.
- `robot_id` 1 and 2 map to the two arm + pipette pairs; each pipette handles only
  one solution, so tips are never exchanged.

## Running

```bash
# schema check only, no hardware, no motion
python -m src.flow.run_flow examples/zif8/zif8_two_solution_mixing_speed5.json --validate-only

# validate + dry run without hardware
python -m src.flow.run_flow examples/zif8/zif8_two_solution_mixing_speed5.json --mock

# real run (ports from .env or flags; see docs/setup.md)
python -m src.flow.run_flow examples/zif8/zif8_two_solution_mixing_speed5.json
```

Substitute `_speed1` or `_speed9` for the other two conditions.

Or load the file in the GUI (`streamlit run src/gui/app.py`) and press Run.

## Process logs

Sample process logs (dispensed masses, sensor CSVs, photographs) from the paper are
not included in this directory yet, except for the monitoring placeholders below. The
per-batch run records — the control sheet, `results.csv` and log folder of each of the
nine batches — are not published yet and will be added here, replacing the
placeholders below, when available.
<!-- TODO: add sample logs / measured masses when ready -->

For data that *is* real and published, see
[`examples/dispensing_stability/`](../dispensing_stability/): 100 repeated 3 mL
water injections weighed on the balance, with the original control script.

### Monitoring sample files (placeholders)

- [`sensor_session_sample.csv`](sensor_session_sample.csv) — **placeholder**
  showing the column layout produced by the IoT sensor dashboard
  (`src/monitoring/dashboard/launch_sensor_dashboard.py`): a header row plus 3
  example rows at the dashboard's 100 ms sampling interval. Values are
  plausible but fabricated, not measurements from an actual run. Note that its
  `uvi` column reads `0` because the LTR390 was left in ALS mode until
  2026-09-08; that column now carries a UV index (float).
- [`sensor_session_sample_tags.csv`](sensor_session_sample_tags.csv) —
  **placeholder** for the companion AprilTag pose-tracking log from the same
  session (`_tags` suffix): a header row plus 2 example rows.

Both files exist only to document the CSV format ahead of time — see
[`src/monitoring/README.md`](../../src/monitoring/README.md#log-format) for
the column reference. They will be replaced with real sensor/marker logs from
a ZIF-8 synthesis session once that data is available.

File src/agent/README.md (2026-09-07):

# `src/agent` — AI agent for experimental-flow generation

Turns a natural-language description of an experiment into a JSON experimental flow
(format: [`docs/experimental-flow.md`](../../docs/experimental-flow.md)) that
`src/flow` validates and executes.

## Files

| File | Role |
|---|---|
| `llm_service.py` | `generate_workflow_from_prompt(text, template=None)` — builds the prompt, calls the LLM, extracts and parses the JSON (one automatic retry if the reply is not valid JSON) |
| `presets/*.json` | Validated flows offered in the GUI and usable as templates for the agent |

## How it works

`SYSTEM_PROMPT` in `llm_service.py` describes the robots (`robot_id` 1–3), every
available action with its parameters and units, three worked examples, and the safety
conventions (return home at the end of each loop and of the flow). The user text is
appended and the model is asked for a single JSON object at temperature 0.

With `template=` (a preset's `template` dict) the model is instructed to change only
the parameters of the given flow and keep the step order — the safest way to derive a
new condition from a procedure already checked on hardware.

The returned dict is **not** trusted: `src/flow/schema.py` validates it before
anything moves, and the GUI shows it for review first.

## Backends

Selected with `LLM_MODE` in `.env` (see `.env.example`):

| `LLM_MODE` | Variables | Notes |
|---|---|---|
| `gemini` (default) | `GEMINI_API_KEY`, `GEMINI_MODEL` (default `gemini-3.5-flash`) | Uses `google-generativeai`, JSON response mode |
| `openai_compatible` | `LLM_BASE_URL`, `LLM_API_KEY`, `LLM_MODEL` | Any server speaking the OpenAI chat-completions API, e.g. a local inference server |

Keys are read only from the environment / `.env`; nothing is hard-coded.

## Usage

```python
from src.agent.llm_service import generate_workflow_from_prompt

flow = generate_workflow_from_prompt("右に90°回転して70mm下降し、5 mL 排出してホームに戻る")
```

The prompt and the built-in examples are in Japanese; the model handles English
instructions as well.

## Adding an action

1. Add the Pydantic model and register it in `LabRobotAction` (`src/flow/schema.py`).
2. Add the dispatch branch in `src/flow/executor.py`.
3. Describe the action, with one example, in `SYSTEM_PROMPT`.

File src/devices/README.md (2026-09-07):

# `src/devices` — instrument drivers and safety wrapper

Two layers:

- **Drivers** (`dobot/`, `picus2/`, `ika/`, `scale/`, `webcam/`): thin, device-specific
  classes that speak the instrument's protocol. They know nothing about experiments.
- **Safety wrapper** (`safety/`): the only layer the flow executor and the AI agent
  ever call. It adds workspace limits, pipette volume tracking, retries, settle
  times and logging on top of the drivers.

The AI agent never generates driver-level code; it only chooses *what* to do, and the
wrapper decides *how*.

## Drivers

| Directory | Instrument | Interface | Library | Main class |
|---|---|---|---|---|
| `dobot/` | Dobot Magician robot arm (+ optional rail / conveyor) | USB serial | `pydobot` (+ small patch in `pydobot_patch.py`) | `PyDobotController` |
| `picus2/` | Sartorius Picus 2 electric pipette (10 mL) | USB serial or Bluetooth LE | `pyserial` / `bleak` | `Picus2Controller` |
| `ika/` | IKA RET control-visc hot-plate stirrer | RS-232C | `pyserial` | `IKAController` |
| `scale/` | Sartorius BCE822i (`BCE8221.py`, used in the paper) and A&D EK-610i (`Ek610i.py`, `scale_controller.py`) balances | RS-232C | `pyserial` | `SerialBalance`, `ScaleController` |
| `webcam/` | USB webcam for process photos | UVC | `opencv-python` | `WebcamController` |

Each directory has its own README (in Japanese) with the command set and a usage
example. Device addresses (COM port, Bluetooth MAC) are always passed in by the
caller; there are no hard-coded addresses.

## Safety wrapper (`safety/`)

| File | Class | Role |
|---|---|---|
| `lab_robot.py` | `LabRobot` | One robot = one arm + optionally one pipette (+ stirrer). Async API used by the executor: `move_xyz`, `move_z`, `move_radial`, `rotate`, `rotate_relative`, `go_home`, `aspirate`, `dispense`, `blow_out`, `move_slider`, `move_conveyer`. Tracks the current pose and the volume held in the tip. |
| `shared_devices.py` | `SharedDevices` | Balance and camera, shared by all robots: `tare_scale`, `measure_weight`, `capture_and_save`. |
| `mock_robot.py` | `MockLabRobot`, `MockSharedDevices` | Same interface as `LabRobot` / `SharedDevices` without hardware; used by `--mock` and the GUI's Mock mode. The mock enforces the same workspace limits and returns realistic weights, so mock runs produce the same records as real ones. |
| `validators/` | `WorkspaceValidator` | XYZ box and joint-1 angle limits, checked before every move. The limits come from the `workspace` section of `config.yaml` in the repository root (`default_workspace_validator()`); edit that file to match your fixtures. |

Construction:

```python
from src.devices.safety.lab_robot import LabRobot
from src.devices.safety.shared_devices import SharedDevices

async with LabRobot(use_dobot=True, use_picus2=True,
                    dobot_port="COM12", picus2_address="COM4",
                    picus2_connection_type="usb") as robot:
    robot.set_current_position_as_home()
    await robot.move_z(-50)
    await robot.aspirate(volume=5.0, speed=5)
    await robot.move_z(50)
    await robot.go_home()

async with SharedDevices(use_scale=True, scale_port="COM9") as shared:
    await shared.tare_scale()
    grams = await shared.measure_weight(stabilization_count=3)
```

Safety behaviour built into the wrapper:

- `aspirate` refuses to exceed 10 mL in the tip; `dispense` refuses to exceed the
  held volume.
- Every target pose is validated against the workspace limits from `config.yaml`;
  a violation raises `WorkspaceViolationError` before the command is sent.
- `initialize()` raises if any device fails to come up (and disconnects whatever did
  connect) rather than returning a status that a caller could ignore and then drive a
  disconnected arm.
- `emergency_stop()` force-stops the Dobot command queue (the move in progress halts
  immediately, the queue is discarded, the conveyor motors stop) and switches the IKA
  heater/stirrer off. `run_flow.py` calls it on Ctrl+C, and commands no further
  motion afterwards.
- Configurable settle times after moves, pipette actions and balance readings
  (`wait_after_*` keyword arguments).
- Pipette connection is retried three times with back-off.
- `cleanup()` (also on `async with` exit or on error) disconnects every device.

## Not included

The vendor DLL-based Dobot driver and the powder-dispenser driver used in other
experiments are not part of this repository; only the `pydobot`-based arm driver is
shipped. `LabRobot(use_powder_dispenser=True)` therefore raises `ImportError`.

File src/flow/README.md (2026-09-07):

# `src/flow` — experimental-flow validation and execution

| File | Role |
|---|---|
| `schema.py` | Pydantic models for every action and for the whole flow (`ExperimentWorkflow`). `python src/flow/schema.py` prints the JSON Schema. |
| `executor.py` | `expand_loops()` flattens `loop_start`/`loop_end`; `execute_step()` dispatches one step to the right robot (`robot_id`) or to the shared devices. |
| `experiment_session.py` | `ExperimentSession` — the safety frame shared by every runner: initialise → run → **emergency stop on Ctrl+C**, go home on error → always disconnect. Robot and shared-device construction go through injectable factories, so mock and real runs use the same frame. |
| `experiment_logger.py` | `ExperimentLogger` — one folder per run under `logs/`, holding `run.log`, `measurements.csv`, `summary.md`, `metadata.json`, `images/` and a copy of the input JSON. |
| `accuracy_logger.py` | `DispenseAccuracyLogger` — pairs each `dispense` with the `measure_weight` that follows it and writes expected/measured mass and error to `dispense_accuracy.csv`. |
| `run_flow.py` | Command-line runner: validate → expand → initialise only the devices the flow needs → execute inside `ExperimentSession` → record every step → clean up. |
| `csv_runner/` | Spreadsheet input path: reads a `parameter,value,note` CSV and runs the fixed two-solution mixing sequence with those values. See below. |

The format itself is documented in [`docs/experimental-flow.md`](../../docs/experimental-flow.md).

## Command line

```bash
# validate only
python -m src.flow.run_flow path/to/flow.json --validate-only

# dry run with simulated devices
python -m src.flow.run_flow path/to/flow.json --mock

# real run; ports from config.yaml, overridable per run
python -m src.flow.run_flow path/to/flow.json \
    --robot1-dobot COM3 --robot1-picus2 COM4 \
    --robot2-dobot COM5 --robot2-picus2 COM6 \
    --scale-port COM8 --camera-index 1

# real run without sensor-CSV/video recording
python -m src.flow.run_flow path/to/flow.json --no-record

# dispensing ethanol rather than water (affects the accuracy CSV only)
python -m src.flow.run_flow path/to/flow.json --liquid-density 0.789
```

Only robots whose `robot_id` appears in the flow are connected; the balance and
camera are connected only if a step needs them.

### Ports and workspace limits

Ports and workspace limits come from `config.yaml` in the repository root — copy
`config.example.yaml` to `config.yaml` and edit it (`config.yaml` is gitignored; if
it is missing the example file is used, and if that is missing too the built-in
defaults in `src/config.py` apply). For a single run the resolution order is:

    command-line flag  >  environment variable (.env)  >  config.yaml  >  defaults

Every move is checked against the `workspace` limits by `WorkspaceValidator`
**before** the robot is commanded — for all robots, and in `--mock` mode too, so a
flow can be screened for out-of-range moves without hardware. A violation aborts
the run before the offending step executes.

### Recording

`--record` starts sensor-CSV recording on the monitoring dashboard (launching it
headless if needed) plus overhead-camera video for the duration of the run. It is
on by default for real runs, off with `--no-record`, and always off with `--mock`.

### What a run leaves behind

Each run creates `logs/<YYYY-MM-DD>/<flow name>_<timestamp>/` containing:

| File | Contents |
|---|---|
| `run.log` | the full console log of the run |
| `measurements.csv` | one row per step: timestamp, elapsed time, action, robot, loop iteration, status, duration, weight, image path, error |
| `summary.md` | human-readable report: outcome, the weight/photo timeline, and every step |
| `metadata.json` | start/end time, status (`completed` / `aborted` / `failed`), error, robots used, step and measurement counts |
| `images/` | photographs taken by `capture_and_save` during this run |
| `<flow>.json` | a copy of the input flow, so the run stays reproducible |
| `dispense_accuracy.csv` | expected vs. measured dispensed mass per `dispense` (only if the flow weighs after dispensing) |

### Interrupting a run

Ctrl+C triggers an **emergency stop**: the Dobot command queue is force-stopped
(the move in progress halts immediately, the queue is discarded and the conveyor
motors stop) and the IKA stirrer/heater is switched off. No further motion is
commanded — in particular the robot is *not* sent home, which would be another
move. Devices are then disconnected and the run is recorded as `aborted`.
On an ordinary error the robots do go home before disconnecting.

## Spreadsheet input (`csv_runner/`)

For the two-solution mixing experiment there is no need to touch JSON at all. Copy
`csv_runner/control.example.csv` to `csv_runner/control.csv`, edit the volumes, Z
descents, angles and pipette speeds in a spreadsheet program, and run:

```bash
python -m src.flow.csv_runner.run_csv --mock      # dry run
python -m src.flow.csv_runner.run_csv             # real run
```

The runner builds the fixed step list — the same shape as
`examples/zif8/zif8_two_solution_mixing_speed*.json` — validates it with
`ExperimentWorkflow` and runs it through `execute_step` inside an `ExperimentSession`,
so the workspace validator, the logging and the run folder are identical to a JSON run.
The dispensed masses are additionally written back to `results.csv` next to the input
sheet. Full documentation: [`docs/csv-runner.md`](../../docs/csv-runner.md).

## Library use

```python
from src.flow.schema import ExperimentWorkflow
from src.flow.executor import execute_step, expand_loops

flow = ExperimentWorkflow(**json_dict)          # raises pydantic.ValidationError if invalid
steps = expand_loops([s.model_dump() for s in flow.steps])
for step in steps:
    await execute_step(step, robots, shared_devices, logger)
```

`robots` is a dict `{robot_id: LabRobot | MockLabRobot}`; `shared_devices` is a
`SharedDevices` (or `None` if the flow uses none). `execute_step` returns the
step's measurement, if any (`{"weight": ...}` or `{"image_path": ...}`), which is
what `run_flow.py` records into `measurements.csv`.

To get the same safety frame in your own script, wrap the body in an
`ExperimentSession`:

```python
from src.flow.experiment_session import ExperimentSession

session = ExperimentSession(mock=False)          # mock=True for simulated devices

async def body():
    robot = await session.add_robot(1, use_picus2=True)
    shared = await session.add_shared(use_scale=True)
    ...                                          # your steps

await session.run(body)                          # emergency stop / go home / cleanup
```

## Tests

```bash
pytest tests/
```

The suite covers schema validation and loop expansion, the workspace validator and
its wiring to `config.yaml`, the `ExperimentSession` safety frame (including that a
cancellation emergency-stops instead of homing), the Dobot force-stop protocol, the
accuracy logger, the run_flow port precedence and the CSV runner (parameter
validation, the generated step list and a full mock run). It needs no hardware.

## Adding an action

1. Define a model in `schema.py` with an `action: Literal["..."]` field and add it to
   `LabRobotAction`.
2. Add an `elif action == "..."` branch in `execute_robot_step` or
   `execute_shared_device_step` (and add the name to `SHARED_DEVICE_ACTIONS` for the
   latter).
3. Implement the behaviour in the safety wrapper (`src/devices/safety`), never in the
   executor.
4. Describe it in the agent prompt (`src/agent/llm_service.py`) and in
   `docs/experimental-flow.md`.

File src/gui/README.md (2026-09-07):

# `src/gui` — browser-based GUI

A Streamlit app for building, reviewing and running experimental flows without
editing JSON by hand.

```bash
streamlit run src/gui/app.py
```

Opens `http://localhost:8501`.

| file | role |
|---|---|
| `app.py` | the Streamlit UI only: flow canvas, presets, AI/voice input, sidebar, progress |
| `runner.py` | all execution logic, Streamlit-free and unit-tested (`tests/test_gui_runner.py`) |
| `analyze_dispense_log.py` | precision/accuracy statistics for a finished run folder |

`app.py` holds no device code: pressing *Run* hands the flow to `runner.FlowRunner`,
which takes exactly the same path as the CLI (`python -m src.flow.run_flow`), so a
flow behaves identically whether it is started from the browser or the terminal.

## Features

- **Flow canvas** — every step of the current flow as an editable card (parameters,
  `robot_id`, reorder, delete); a toolbox adds new steps.
- **Presets** — load a validated flow from `src/agent/presets/`.
- **AI generation** — describe the experiment in natural language; the agent
  (`src/agent`) returns a flow that is shown in the canvas for review before running.
  Optionally start from a preset and let the agent change only its parameters.
- **Voice input** — microphone button next to each text box; transcription by
  `src/voice`.
- **Validation before execution** — the flow is checked against the Pydantic schema
  (`src/flow/schema.py`) and its loops are expanded *before* any device is opened.
  A flow that fails validation is refused: the errors are listed in the UI (one line
  per offending step) and no `ExperimentSession` is created. Flows arriving from the
  agent, a preset or an uploaded JSON file are validated on arrival as well, and the
  *Validate* button re-checks the current canvas without running it.
- **Mock / Real** — *Mock* runs the whole flow against `MockLabRobot` /
  `MockSharedDevices`, writing the same log folder as a real run; nothing is recorded
  and the safety gate is not queried. *Real* drives the instruments.
- **Stop** — cancels the running flow. Cancellation lands in `ExperimentSession`'s
  abort path, the same one Ctrl+C takes on the CLI: every robot is emergency-stopped,
  all devices are disconnected, and the run folder is finalised with
  `status: aborted`. (There is no separate "emergency stop" that leaves the run
  half-finished behind.)
- **Progress and log** — a progress bar (`n/total` steps) and the step-by-step log,
  including the device-level messages (balance readings, image paths).
- **Monitoring hook** — in Real mode, if the sensor dashboard (`src/monitoring`) is
  reachable at `SENSOR_SERVER_URL` (default `http://localhost:8000`), recording is
  started before the run and stopped after it, and the dashboard's `/api/is_safe`
  check gates every step (an unreachable dashboard does not block the run).

## Device settings (sidebar)

Ports and the camera index default to **`config.yaml`** in the repository root
(falling back to the tracked `config.example.yaml`), read through `src.config` — the
same source the CLI uses, so the GUI and the CLI cannot drift apart. Edits in the
sidebar apply to the current browser session only; *↺ config.yaml の値に戻す* restores
the file's values. For a permanent change, edit `config.yaml`.

Only the devices the flow actually uses are opened: robots are taken from the
`robot_id` of the steps, the pipette from `aspirate`/`dispense`/`blow_out`, the
balance from `measure_weight`/`tare_scale` and the camera from `capture_and_save`.

## What a run leaves behind

Every run — from the GUI or the CLI, mock or real — creates

```
logs/<date>/<flow name>_<timestamp>/
    run.log               every log line of the run
    <flow>.json           a copy of the flow that was executed
    measurements.csv      one row per step (weight, image path, status, duration)
    dispense_accuracy.csv each dispense paired with the mass weighed after it
    metadata.json         start/end, status, robots used, counts
    summary.md            human-readable report
    images/               pictures taken by capture_and_save
```

The folder is shown under the progress bar while the run is in progress.

To get the statistics of a dispensing run (mean, SD, variance, CV as the
repeatability figure, and the bias against the nominal mass as the trueness figure):

```bash
python -m src.gui.analyze_dispense_log logs/<date>/<flow name>_<timestamp>
python -m src.gui.analyze_dispense_log <run folder> --volume 5 --density 0.998
```

It reads `dispense_accuracy.csv` and falls back to the `weight_g` column of
`measurements.csv`, so it works for any run that weighed something.

## How the run is driven (and why)

Streamlit re-runs the whole script on every interaction, so the run cannot simply
block the script — but slicing it into one step per re-run would mean keeping live
device handles in `st.session_state` and re-implementing the safety frame around
them. Instead `FlowRunner` executes the flow in **one background thread with one
asyncio event loop**, entirely inside `ExperimentSession.run()`, and publishes
`ProgressEvent`s on a queue; the Streamlit script drains that queue and re-runs
itself every ~0.4 s while the thread is alive. *Stop* cancels the asyncio task from
the outside. The run thread never touches the Streamlit API, which is also why
`runner.py` can be tested without a browser.

## Requirements

`streamlit`, `streamlit-mic-recorder` (voice button) and the modules in `src/agent`,
`src/voice`, `src/flow`, `src/devices`. The app degrades gracefully: without an LLM
key the AI button shows a hint; without `ffmpeg`/whisper the microphone is hidden.

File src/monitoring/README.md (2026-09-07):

# Monitoring

IoT environmental sensor logging and process video recording for the automated
synthesis platform. A Raspberry Pi Zero WH + Waveshare Environment Sensor HAT
pushes sensor readings to the control PC, where a small FastAPI service
records them (plus an overhead-camera AprilTag pose track) to CSV; a separate
OpenCV helper records the overhead-camera video itself.

## Overview

```
 ┌────────────────────┐        TCP :50001            ┌───────────────────────────────────┐
 │ Raspberry Pi        │  JSON Lines, ~10 Hz          │ Control PC                          │
 │ pi/pi_sensor_agent  │ ────────────────────────────>│ dashboard/launch_sensor_dashboard   │
 │  (I2C sensor reads)  │                              │  FastAPI :8000  +  TCP server :50001│
 └────────────────────┘                              │                                      │
                                                       │  latest_sensor_data ──┐              │
                                                       │                       ▼              │
                                                       │              recording_loop (100 ms) │
                                                       │                       │              │
                                                       │                       ▼              │
                                                       │              CSV (sensor + tags)     │
                                                       └───────────────────────────────────┘
                    browser (dashboard UI)                       ▲        ▲
                        │  camera frames                          │        │
                        └── POST /api/detect_tags ─────────────────┘        │
                        └── POST /api/upload_video (webm) ───────────────────┘

 src/flow/run_flow.py, src/gui/app.py or any external process
        │
        └── POST /api/start , POST /api/end  ────────► start/stop a recording session

 camera/video_recorder.py  (on the control PC, independent of the dashboard)
        └── OpenCV VideoCapture(camera_index) ──► .mp4 (overhead process video)
```

Two recording paths run independently:

1. **Sensor + AprilTag CSV logging** — `dashboard/launch_sensor_dashboard.py`
   receives sensor pushes over TCP, serves a browser dashboard over HTTP, and
   (while a recording session is active) writes one CSV row per Pi every
   100 ms plus AprilTag pose rows whenever the browser posts a camera frame
   to `/api/detect_tags`.
2. **Overhead video recording** — `camera/video_recorder.py` opens an OpenCV
   `VideoCapture` on the process camera and writes an `.mp4` on its own
   thread. It has no dependency on the dashboard and can be started/stopped
   independently (e.g. from `src/flow/run_flow.py`).

## Measured quantities

| Quantity | Sensor | I2C address | CSV column(s) |
|---|---|---|---|
| Temperature | BME280 | `0x76` | `temperature` (°C) |
| Humidity | BME280 | `0x76` | `humidity` (%RH) |
| Illuminance | TSL25911 | `0x29` | `lux` |
| UV | LTR390 | `0x53` | `uvi` (UV index) |
| VOC | SGP40 | `0x59` | `voc_raw` (raw signal, not the VOC index) |
| 3-axis acceleration | ICM20948 | `0x68` | `acc_x`, `acc_y`, `acc_z` (g) |
| 3-axis angular velocity | ICM20948 | `0x68` | `gyro_x`, `gyro_y`, `gyro_z` (deg/s) |

**The magnetometer (AK09916, embedded in the ICM20948 package) is not read in
this version.** Only the ICM20948's accelerometer and gyroscope are used.

**UV column semantics changed on 2026-09-08.** Recordings made before that date
were taken with the LTR390 in ALS mode, in which the UVS data registers never
update, so their `uvi` column is `0` throughout. The Pi agent now initialises
the sensor in UVS mode (20-bit, gain 3, 1000 ms measurement rate) and `uvi`
holds a UV index as a float. The column name is unchanged so older CSV files
remain parseable. Because a 20-bit conversion takes 400 ms, the value updates
about once a second even though the agent samples every 100 ms.

## Raspberry Pi setup

1. Flash **Raspberry Pi OS Lite (Bookworm, 32-bit)** to the SD card with
   [Raspberry Pi Imager](https://www.raspberrypi.com/software/). Use the
   Imager's own settings (gear icon / "Edit Settings") to set the hostname,
   create a user, and configure Wi-Fi — **never commit these credentials to
   the repository.**
2. Boot the Pi, SSH in, and enable I2C:
   ```bash
   sudo raspi-config
   # Interface Options -> I2C -> Enable
   ```
3. Install the I2C tools and Python bus library:
   ```bash
   sudo apt update
   sudo apt install -y python3-smbus i2c-tools
   ```
4. Power off the Pi and mount the Waveshare Environment Sensor HAT on the
   40-pin GPIO header.
5. Boot again and verify the sensors are visible on the bus:
   ```bash
   i2cdetect -y 1
   ```
   Expected addresses: `0x29` (TSL25911), `0x53` (LTR390), `0x59` (SGP40),
   `0x68` (ICM20948), `0x76` (BME280).
6. Copy the agent and service files from this repository to the Pi (see
   [Installing the agent](#installing-the-agent) below), or do it manually:
   ```bash
   scp src/monitoring/pi/pi_sensor_agent.py pi@<pi-host>:~/pi_sensor_agent.py
   ```
7. Create `/etc/sensor-agent.env` on the Pi from
   [`pi/sensor-agent.env.example`](pi/sensor-agent.env.example), filling in
   your control PC's address:
   ```bash
   ssh pi@<pi-host> "sudo tee /etc/sensor-agent.env >/dev/null" < src/monitoring/pi/sensor-agent.env.example
   ssh pi@<pi-host> "sudo chmod 600 /etc/sensor-agent.env"
   # then edit SENSOR_AGENT_PC_HOST on the Pi to your PC's real address
   ```
8. Install and enable the systemd service:
   ```bash
   ssh pi@<pi-host> "sudo cp ~/sensor-agent.service /etc/systemd/system/ && \
       sudo systemctl daemon-reload && sudo systemctl enable --now sensor-agent"
   ```
9. Check it is running and reconnecting correctly:
   ```bash
   ssh pi@<pi-host> "journalctl -u sensor-agent -f"
   ```

### Installing the agent

[`pi/install_pi_agent.ps1`](pi/install_pi_agent.ps1) automates steps 6-8 from
a Windows control PC:

```powershell
.\src\monitoring\pi\install_pi_agent.ps1 -User pi -HostName raspberrypi.local -PcHost 192.0.2.10
```

This copies `pi_sensor_agent.py`, renders `sensor-agent.service` with `%i`
substituted for the given user, renders `/etc/sensor-agent.env` with the
given `-PcHost`/`-PcPort`, and enables the service over SSH. Run it once per
Pi; after that, the agent starts automatically on every boot and reconnects
to the PC whenever the connection drops. Re-run the script (or just update
`/etc/sensor-agent.env` and `systemctl restart sensor-agent`) if the control
PC's address changes.

## Network

- The Pi and the control PC must be reachable on the same LAN. Any LAN
  works — the reference setup used a Windows mobile hotspot hosted by the
  control PC, mainly because it makes the PC's gateway address predictable
  and keeps mDNS (`*.local`) hostname resolution reliable without depending
  on lab infrastructure, but a normal router or switch works identically.
- The Pi's target address is configured on the Pi side, via
  `SENSOR_AGENT_PC_HOST` in `/etc/sensor-agent.env` — **not** hardcoded in
  `pi_sensor_agent.py`. There is no default; the agent exits with an error if
  the variable is unset and no `--host` argument is given.
- The dashboard's web server listens on `127.0.0.1` (loopback only) by
  default — a remote browser cannot reach it and the recording-control API is
  not exposed to the LAN. To open the dashboard from another machine's
  browser:
  1. Set `SENSOR_DASHBOARD_HOST=0.0.0.0` (or a specific LAN IP) in the
     control PC's environment.
  2. Set `SENSOR_DASHBOARD_TOKEN` to a random secret — once set, `/api/start`
     and `/api/end` require it (as an `X-Auth-Token` header), and so do the
     `start_recording` / `stop_recording` commands on the `/ws` WebSocket.
  3. If the browser's URL uses a LAN IP rather than `localhost`, add that IP
     to `SENSOR_DASHBOARD_ALLOWED_HOSTS` (comma-separated) so it passes the
     Host-header allow-list. The same list also gates the WebSocket's `Origin`
     header, so a remote browser will not connect without this step.
  4. Open the dashboard once as `http://<host>:8000/?token=<secret>` so the
     page can authenticate its WebSocket; see [Dashboard security](#dashboard-security).
  5. Allow inbound TCP `8000` (dashboard) and `50001` (Pi sensor pushes)
     through the PC's firewall.

## Dashboard security

The dashboard can start and stop recordings and choose the directory CSV files
are written to, so the following protections apply to the `/ws` WebSocket as
well as to the HTTP API:

- **Host-header allow-list** (always on). `TrustedHostMiddleware` rejects
  requests whose `Host` is not `localhost`, `127.0.0.1`, `::1`, the configured
  bind address, or an entry of `SENSOR_DASHBOARD_ALLOWED_HOSTS`. This is the
  standard defence against DNS rebinding.
- **WebSocket `Origin` check** (always on). A `/ws` handshake is closed with
  code `1008` unless its `Origin` host is in that same allow-list. Browsers do
  not apply the same-origin policy to WebSockets, so without this check any web
  page the operator happens to visit could open `ws://localhost:8000/ws` and
  drive `update_config` + `start_recording` to write files to a directory of
  its choosing (cross-site WebSocket hijacking). A handshake with **no**
  `Origin` header is a non-browser client (curl, the flow runner, a test) and is
  accepted only from the local machine.
- **Token on recording control.** When `SENSOR_DASHBOARD_TOKEN` is set,
  `start_recording` / `stop_recording` over `/ws` require it — either as a
  `?token=<secret>` query parameter on the WebSocket URL or as a `"token"`
  field in the message — exactly as `POST /api/start` requires `X-Auth-Token`.
  When no token is configured (the localhost-only default), those two actions
  are restricted to local clients.
- **Local-only privileged actions** (always on). `update_config`,
  `pick_folder` and `open_folder` are refused for any non-loopback client
  regardless of the token.
- **Upload size limit.** `POST /api/upload_video` stops at 200 MB and returns
  HTTP 413, deleting the partial file; override with
  `SENSOR_DASHBOARD_MAX_UPLOAD_BYTES`.

The browser front end has no token input field. Open the dashboard once as
`http://<host>:8000/?token=<secret>` — `static/app.js` stores the value in
`localStorage` under the key `sensorDashboardToken` and reuses it on every
later visit and reconnect (you can also set that key from the browser console).
Rejected commands are reported back on the WebSocket as
`{"type": "error", "action": ..., "detail": ...}` and appear in the page's log
panel.
- The TCP sensor listener (`SENSOR_DASHBOARD_TCP_HOST`, default `0.0.0.0`)
  always listens on all interfaces, since the Pi is necessarily a separate
  host — there is no loopback-only mode for it.

## Running the dashboard on the PC

```bash
pip install -r src/monitoring/requirements.txt
python src/monitoring/dashboard/launch_sensor_dashboard.py
```

This calls `uvicorn.run(app, host=WEB_HOST, port=WEB_PORT)` directly from the
script's `__main__` block (rather than the `uvicorn` CLI), using the host/port
resolved as described above. By default it also opens the dashboard in a
browser about 1.5 s after startup; set `SENSOR_DASHBOARD_HEADLESS=1` to skip
that (e.g. when running on a headless machine or under a process supervisor).

Port numbers come from `src/monitoring/config.yaml` if present, else from
[`config.example.yaml`](config.example.yaml), else from the built-in defaults
`web_port: 8000` / `tcp_port: 50001`. `config.yaml` is gitignored — copy
`config.example.yaml` to `config.yaml` in this directory to override the
ports locally without touching version control. Whatever `tcp_port` is
configured on the PC must match `SENSOR_AGENT_PC_PORT` in every Pi's
`/etc/sensor-agent.env`.

Recordings are written under `experiment_data/` at the repository root by
default; override with `SENSOR_DASHBOARD_DATA_DIR`.

## Log format

Each recording session produces up to three files in the save directory,
named from the session start time and an optional experiment-name prefix
(from `POST /api/start`'s `experiment_name`, sanitized to `[A-Za-z0-9_-]`):

- `{prefix}session_YYYYMMDD_HHMMSS.csv` — sensor readings
- `{prefix}session_YYYYMMDD_HHMMSS_tags.csv` — AprilTag poses
- `{prefix}session_YYYYMMDD_HHMMSS.webm` — optional, only if the browser's
  in-page webcam recorder was used (`POST /api/upload_video`)

The sensor CSV is written by sampling `latest_sensor_data` (the most recent
message received from each Pi) every 100 ms, regardless of each Pi's own
push rate — so a slow or bursty Pi still produces one row per tick, holding
its last known value. See [`examples/zif8/`](../../examples/zif8/) for sample
files (`sensor_session_sample.csv`, `sensor_session_sample_tags.csv`) showing
this layout; they are placeholders, not measurements from an actual run.

### Sensor CSV columns

| Column | Meaning |
|---|---|
| `timestamp` | ISO 8601, UTC, with offset (e.g. `2026-01-01T03:00:00.000000+00:00`) |
| `hostname` | Reporting Pi's hostname |
| `temperature` | °C |
| `humidity` | %RH |
| `lux` | Illuminance |
| `uvi` | UV index (float); `0` in every recording made before 2026-09-08, see [Measured quantities](#measured-quantities) |
| `voc_raw` | VOC, raw sensor signal |
| `acc_x`, `acc_y`, `acc_z` | Acceleration, g |
| `gyro_x`, `gyro_y`, `gyro_z` | Angular velocity, deg/s |

### Tags CSV columns

| Column | Meaning |
|---|---|
| `timestamp` | ISO 8601, UTC, with offset |
| `tag_id` | Detected AprilTag (36h11) ID |
| `tx_mm`, `ty_mm`, `tz_mm` | Translation relative to the camera, mm |
| `roll`, `pitch`, `yaw` | Rotation relative to the camera, degrees |
| `dx_mm`, `dy_mm`, `dz_mm` | Translation relative to this tag's zero reference, mm (blank if no zero has been set) |
| `droll`, `dpitch`, `dyaw` | Rotation relative to the zero reference, degrees (blank if no zero has been set) |
| `outlier` | `1` if this sample's pose jump was rejected and the previous smoothed pose was held instead, else `0` |

The camera's intrinsics are an approximation (`fx ≈ 0.85 × frame width`), so
absolute `t*_mm` values carry a distance-dependent bias; relative motion and
angles (and the zero-referenced `d*` columns) are the more reliable readout.

## Overhead camera recording

```python
from src.monitoring.camera.video_recorder import VideoRecorder

recorder = VideoRecorder(
    output_path="experiment_data/session_20260101_120000.mp4",
    camera_index=1,   # see config.yaml's video.camera_index
)
recorder.start()
# ... run the experiment ...
saved_path = recorder.stop()
```

`camera_index` is the OpenCV device index for the Logitech C920n mounted
above the setup; it is platform- and machine-dependent (probe with a short
OpenCV script if recordings come from the wrong camera). The recorder runs on
its own background thread and paces frames to the camera's own reported FPS.

## HTTP API

The dashboard exposes an HTTP API — used by the GUI (`src/gui/app.py`) and the flow runner to
start and stop recording, and available to any other program on the LAN to
read live sensor values. See [`dashboard/API.md`](dashboard/API.md) for the
full endpoint reference, request/response examples, and authentication
notes.

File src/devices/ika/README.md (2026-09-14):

# IKA撹拌装置制御モジュール

このモジュールは実験自動化システムにおいてIKA RET Control-viscホットスターラーをシリアル通信で制御するためのクラスと関数を提供します。

## 概要

`ika_controller.py`はIKAホットスターラーを操作するためのインターフェースを提供します。主な機能には以下が含まれます：

- シリアル接続管理
- 温度制御
- 撹拌速度制御
- 重量測定（RET control-visc のみ。下記の注意を参照）
- データ記録とグラフ表示

このモジュールを使用することで、実験の温度・撹拌を正確に制御し、リアルタイムでのモニタリングが可能になります。

## 使用方法

### 基本的な使用例

```python
from src.devices.ika.ika_controller import IKAController
import time

# IKAコントローラーの初期化（ポート名を指定）
device = IKAController(port='COM8')

# デバイスのリセット（任意）
device.reset_device()

# 温度と撹拌速度を設定して撹拌開始（摂氏40度、速度100rpm）
device.start_stirring(40, 100)

# 5分間撹拌
time.sleep(300)

# 撹拌停止
device.stop_stirring()

# 接続を閉じる
device.close()
```

### 温度制御とモニタリング

```python
# 温度40℃、撹拌速度100rpmで10分間動作（グラフ表示あり）
temperatures, times = device.set_temperature(40, 100, 10)

# 温度40℃、撹拌速度100rpmで10分間動作（グラフ表示なし）
device.stirring_at_temperature(40, 100, 10)
```

### 重量測定

```python
# 重量を測定
weight = device.measure_weight()
print(f"測定された重量: {weight}")
```

### 実験パラメータを使用した制御

```python
from src.devices.ika.ika_controller import IKAController, run_temperature_experiment

# IKAコントローラーの初期化
device = IKAController(port='COM17')

# 実験パラメータの定義
params = {
    "temperature": 45,        # 設定温度（℃）
    "stabilize_speed": 200,   # 安定化フェーズでの撹拌速度（rpm）
    "stabilize_minute": 5,    # 安定化フェーズの時間（分）
    "stirring_speed": 150,    # 撹拌フェーズでの撹拌速度（rpm）
    "stirring_minute": 15     # 撹拌フェーズの時間（分）
}

# 実験の実行
temperatures, times = run_temperature_experiment(device, params)

# データをPandasデータフレームに変換してCSVに保存
import pandas as pd
data = pd.DataFrame({
    "Time (minutes)": times,
    "Temperature (°C)": temperatures
})
data.to_csv("experiment_data.csv", index=False)
```

## 主要機能

### 接続管理

- `__init__(port, baudrate, timeout)` - コントローラーの初期化とシリアル接続
- `is_connected()` - 接続状態を確認する
- `send_command(command)` - コマンドを送信する
- `close()` - シリアルポートを閉じる

### デバイス制御

- `reset_device()` - デバイスをリセットする
- `start_pc_mode(X)` - PCモードを開始する（X：モード番号）
- `stop_pc_mode(X)` - PCモードを停止する（X：モード番号）
- `read_data(X)` - 装置からデータを読み取る（X：読み取りモード番号）

### 撹拌と温度制御

- `set_stirring_speed(speed)` - 撹拌速度を設定する
- `start_stirring(temperature, speed)` - 温度と撹拌速度を設定して撹拌開始
- `stop_stirring()` - 撹拌と温度制御を停止する
- `set_temperature(temperature, speed, wait_minute)` - 温度と撹拌速度を設定し、指定時間動作させる（グラフ表示あり）
- `stirring_at_temperature(temperature, speed, wait_minute)` - 温度と撹拌速度を設定し、指定時間動作させる（グラフ表示なし）

### 重量測定

- `check_weight_function_ready()` - 重量測定機能の準備状況を確認する
- `wait_for_weight_function_ready(max_wait_time, check_interval)` - 重量測定機能が準備できるまで待機する
- `measure_weight()` - 装置の計量機能で重量を測定する

### 実験ユーティリティ

- `run_temperature_experiment(device, params)` - 温度実験を実行する関数

## IKAコマンド仕様

以下に主要なIKAコマンドを示します：

- `RESET` - デバイスをリセットする
- `START_X` - PCモードXを開始する（X：モード番号）
- `STOP_X` - PCモードXを停止する（X：モード番号）
- `IN_PV_X` - モードXの現在値を読み取る（X：モード番号）
- `OUT_SP_X Y` - モードXの設定値をYに設定する（X：モード番号、Y：設定値）
- `STATUS_X` - モードXの状態を取得する（X：モード番号）

### モード番号

- `2` - 温度制御モード
- `4` - 撹拌速度制御モード
- `90` - 重量測定モード

## データ記録とグラフ表示

`set_temperature()`メソッドは実験中の温度データをリアルタイムでグラフ表示し、実験終了後にデータを返します。このデータはCSVファイルに保存するなど、さらなる分析に利用できます。

```python
# データをCSVに保存
import pandas as pd
import os
from datetime import datetime

# 現在の日時をフォルダ名として使用
current_time = datetime.now().strftime("%Y%m%d_%H%M")
folder_name = f"data_{current_time}"
os.makedirs(folder_name, exist_ok=True)

data = pd.DataFrame({
    "Time (minutes)": times,
    "Temperature (°C)": temperatures
})

file_name = "temperature_data.csv"
data.to_csv(os.path.join(folder_name, file_name), index=False)
```

## 注意点

- **重量測定機能は実験フローでは使っていません。** RET control-visc 内蔵の計量機能は
  計量範囲 10–5000 g、精度 ±(0.3 % + 2) g（IKA 公表値）で、数 g の分注量を評価するには
  粗すぎます。質量測定はすべて電子天秤（`src/devices/scale/`）で行います。
  `measure_weight()` 等は RET control-visc でしか動作せず、互換性のために残してあるだけです。
  撹拌・温度制御のコマンド（`OUT_SP_2`, `OUT_SP_4`, `START_x`, `STOP_x`, `IN_PV_x`）は
  IKA の NAMUR コマンド共通なので、RS-232/USB 付きの安価な機種（例: IKA Plate (RCT digital)）
  でも使えるはずです。ただし RCT digital での動作確認はまだ行っていません。
- シリアルポート名（COM8など）は環境によって異なります。デバイスマネージャーなどで確認してください。
- 温度制御は外部環境の影響を受けるため、設定温度に到達するまでに時間がかかる場合があります。
- 長時間の実験では、データのバックアップを定期的に行うことをお勧めします。
- 撹拌速度は0〜1000rpmの範囲で設定可能ですが、液体の粘度や容器によって適切な値は異なります。

## 依存関係

- `serial` - シリアル通信
- `time` - 時間制御
- `matplotlib` - グラフ表示
- `pandas` - データ処理（オプション）
- `datetime` - 日時処理
- `os` - ファイル操作

## トラブルシューティング

- 接続エラーが発生した場合、正しいポート名を指定しているか、デバイスの電源が入っているかを確認してください。
- グラフ表示に問題がある場合、`matplotlib.use("TkAgg")`を環境に合わせて変更してください（例：`Qt5Agg`）。
- 温度が安定しない場合、周囲環境や使用する液体の量、容器の材質を確認してください。

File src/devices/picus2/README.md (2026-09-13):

# Picus2電動ピペット制御モジュール

このモジュールは実験自動化システムにおいてPicus2電動ピペットを USB シリアルまたは Bluetooth 経由で制御するためのクラスと関数を提供します。

## 概要

`picus2_controller.py`はPicus2電動ピペットを操作するための非同期インターフェースを提供します。主な機能には以下が含まれます：

- Bluetooth接続管理
- ボタン操作のエミュレーション
- 液体の吸引・吐出
- チップの排出
- 液体の完全排出（ブローアウト）
- 液体の混合

このモジュールは`asyncio`と`bleak`ライブラリを使用した非同期通信を採用しています。

## 使用方法

### 基本的な使用例

```python
import asyncio
from picus2.picus2_controller import Picus2Controller, Buttons

async def main():
    # Picus2コントローラーの初期化（BluetoothMACアドレスを指定）
    picus = Picus2Controller("XX:XX:XX:XX:XX:XX")
    
    # 接続
    await picus.connect()
    
    try:
        # モーターモードを有効化
        await picus.set_motor_mode(True)
        
        # 5mLを吸引（速度5）
        await picus.aspirate(amount=5.0, speed=5)
        
        # 5mLを吐出（速度5）
        await picus.dispense(amount=5.0, speed=5)
        
        # 残液を完全に排出
        await picus.blow_out()
        
        # チップを排出
        await picus.eject_tip()
        
    finally:
        # モーターモードを無効化
        await picus.set_motor_mode(False)
        
        # 切断
        await picus.disconnect()

# 非同期関数を実行
asyncio.run(main())
```

### ボタン操作

```python
# 特定のボタンを押す
await picus.button(Buttons.TRIGGER_BUTTON_POWER)
await picus.button(Buttons.TRIGGER_BUTTON_LEFT)
await picus.button(Buttons.TRIGGER_BUTTON_RIGHT)
```

### 液体混合

```python
# 5回、速度5で3.0mLの液体を混合
await picus.mix(cycles=5, speed=5, amount=3.0)
```

## 主要機能

### 接続管理

- `connect()` - Picus2に接続する
- `disconnect()` - Picus2から切断する
- `send_command(command)` - コマンドを送信する

### ボタン操作

- `button(button, interval)` - 指定したボタンを押す

### モーター制御

- `set_motor_mode(mode)` - モーターモードを設定する

### 液体操作

- `aspirate(amount, speed)` - 液体を吸引する
- `dispense(amount, speed)` - 液体を吐出する
- `blow_out(go_home, speed, delay_ms)` - 液体をすべて排出する
- `mix(cycles, speed, amount)` - 液体を混合する
- `eject_tip()` - チップを排出する

### ユーティリティ

- `calculate_operation_time(amount, speed)` - ピペット操作にかかる時間を計算する
- `wait_until_END_received()` - ENDメッセージが受信されるまで待機する
- `debug_print(message)` - デバッグメッセージを出力する

## ボタン定数

`Buttons`クラスは以下の定数を提供します：

- `TRIGGER_BUTTON_POWER` - 電源ボタン
- `TRIGGER_BUTTON_LEFT` - 左ボタン
- `TRIGGER_BUTTON_MIDDLE` - 中央ボタン
- `TRIGGER_BUTTON_RIGHT` - 右ボタン
- `TRIGGER_BUTTON_TOP` - 上部トリガーボタン
- `TRIGGER_BUTTON_PRESET` - プリセットボタン
- `TRIGGER_BUTTON_TIPEJECT` - チップ排出ボタン
- `UP` - 上方向ボタン
- `DOWN` - 下方向ボタン

## 注意点

### BluetoothMACアドレスの取得

Picus2のBluetoothMACアドレスを取得するには：

1. ピペットのBluetoothを有効にする
2. コンピュータのBluetoothスキャンを使用して検出する
3. デバイス情報からMACアドレスを確認する（例: "XX:XX:XX:XX:XX:XX"）

### 非同期プログラミング

このモジュールはPython `asyncio`を使用した非同期プログラミングを採用しています：

- 全ての操作メソッドは`async def`で定義されており、`await`キーワードで呼び出す必要があります
- メインスクリプトも非同期関数として定義し、`asyncio.run()`で実行する必要があります

### デバッグモード

デバッグが必要な場合は以下のように設定できます：

```python
picus = Picus2Controller("XX:XX:XX:XX:XX:XX")
picus.DEBUG = True  # デバッグ出力を有効化
```

### オペレーション時間

吸引・吐出などの操作は一定時間を要します。`calculate_operation_time()`メソッドは操作にかかる推定時間を計算し、その時間が経過するまで待機します。速度（1-9）と量（mL）に基づいて計算されます。

## 依存関係

- `asyncio` - 非同期処理
- `bleak` - Bluetooth Low Energy通信
- `random` - テスト用のランダム値生成
- `time` - 時間計測

## トラブルシューティング

- 接続エラーが発生した場合、Picus2のバッテリーが十分であることと、Bluetoothが有効になっていることを確認してください。
- 「モーターモードを有効にしてください」というエラーが表示された場合、操作前に`set_motor_mode(True)`を呼び出してください。
- 操作が完了しない場合、操作時間の計算が不正確な可能性があります。実際の操作時間に合わせて待機時間を調整してください。

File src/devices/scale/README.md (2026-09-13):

# 電子天びん制御モジュール

A&D EK-610i 系電子天びんをRS-232C経由で操作するためのコントローラーです。

## 特徴

- **高精度測定**: 0.01g精度での重量測定
- **安定化測定**: 複数回測定による平均値取得
- **風袋引き機能**: ゼロ点リセット機能
- **コンテキストマネージャー対応**: 自動接続・切断管理
- **エラーハンドリング**: 包括的な例外処理

## 使用方法

### 基本的な使用例

```python
from src.devices.scale import ScaleController

# コンテキストマネージャーとして使用（推奨）
with ScaleController(port="COM3") as scale:
    # 風袋引き
    scale.tare()
    
    # 重量測定
    weight = scale.query_weight()
    print(f"重量: {weight:.3f} g")
    
    # 安定した重量取得
    stable_weight = scale.get_stable_weight(samples=5)
    print(f"安定重量: {stable_weight:.3f} g")
```

### 手動接続・切断

```python
scale = ScaleController(port="COM3")

try:
    # 接続
    if scale.connect():
        # 測定
        weight = scale.query_weight()
        print(f"重量: {weight:.3f} g")
finally:
    # 切断
    scale.disconnect()
```

## API リファレンス

### ScaleController

電子天びん制御のメインクラス

#### コンストラクタ

```python
ScaleController(port="COM3", baudrate=2400, bytesize=7, parity="even", stopbits=1)
```

#### メソッド

- `connect() -> bool`: デバイスに接続
- `disconnect()`: デバイスから切断  
- `is_connected() -> bool`: 接続状態確認
- `query_weight() -> float`: 重量測定（単発）
- `tare(delay=0.5) -> bool`: 風袋引き
- `get_stable_weight(samples=3, interval=0.1) -> float`: 安定重量測定

## 通信仕様

- **ポート**: RS-232C
- **ボーレート**: 2400 bps
- **データビット**: 7 bit
- **パリティ**: Even
- **ストップビット**: 1 bit
- **フロー制御**: なし

## エラー処理

以下の例外が発生する可能性があります：

- `ConnectionError`: デバイス接続エラー
- `TimeoutError`: 応答タイムアウト
- `ValueError`: データ解析エラー

## ログ

デバッグレベルでの詳細ログと、INFOレベルでの操作ログを出力します。

```python
import logging
logging.basicConfig(level=logging.INFO)
```

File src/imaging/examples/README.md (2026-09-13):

# Example run

One complete example run, `zif8_vial_5s/`, kept here so that `make_panel.py`
can be tried without a camera. It is the source of the photograph in the
paper's Figure 6(b) and of the panel layout in Figure 6(c, d).

| | |
|---|---|
| Sample | ZIF-8 (a metal-organic framework) suspension — white sediment under a clear supernatant — synthesised by the platform on 2026-07-02 |
| Vessel / mixing | screw-top vial, **not** stirred during synthesis |
| Dispensing | the second precursor solution ("solution 2") dispensed over **5 s** |
| Photographed | 2026-07-14 13:25 (`captured_at` `20260714_132511`), twelve days after synthesis, once the suspension had settled |
| Camera | Logitech C920n, gain 0, focus 180, white balance manual 4600 K; **exposure was still at the older, brighter setting used before this module's reference exposure of 20** (see caveats) |
| Light | NEEWER RGB62 — white 5600 K for geometry, then HSI red/green/blue at 1 % intensity |
| Geometry (auto-detected, not locked) | `meniscus_y` 359, `sediment_front_y` 474, `liquid_bottom_y` 620, body columns 632–744, fill fraction 0.708 |

Contents (one run directory as written by `acquire.py`):

- `ref_white.jpg` — white-light reference photo (used for geometry detection)
- `shot_red.jpg`, `shot_green.jpg`, `shot_blue.jpg` — monochromatic captures
  at nominal 625 / 525 / 465 nm
- `profiles.csv` — per-row optical density (OD) for each wavelength
- `spectral.png` — OD-vs-depth figure generated by `acquire.py`
- `summary.json` — capture metadata (geometry, LED intensity, warnings, etc.)

The `"warning"` strings in `summary.json` were translated to English from the
original Japanese capture logs; no other field was modified.

Render the panel with:

```
python3 make_panel.py examples/zif8_vial_5s --out /tmp/panels
```

(the run directory is resolved relative to the current directory first and
then to `src/imaging/`, so the same command also works from the repository
root as `python3 src/imaging/make_panel.py examples/zif8_vial_5s`.)

## Data caveats

This run is published as a **worked example of the imaging pipeline**, not as
a validated measurement. Specifically:

- **The white reference is clipped.** 43 % of the liquid rows are saturated
  in the metering channel of `ref_white.jpg` (the whole clear supernatant
  region). `make_panel.py` therefore draws no white transmittance curve by
  default and shows the white photograph for visual reference only;
  `--with-white` plots it anyway, dashed over the saturated rows. Every run
  in this measurement batch has a white reference clipped between 62 % and
  90 % over the vial-neck region, which is why this batch should be re-measured
  with a lower white intensity.
- **The 465 nm channel is clipped too.** Its secondary (G) channel saturates
  over 39 % of the liquid rows, again in the clear supernatant. Where the
  465 nm curve sits at T ≈ 1 it is reporting a clipped sensor reading, not a
  measured transmittance. The 625 nm and 525 nm curves are unclipped over
  the full depth range.
- **Old exposure setting.** This batch was photographed before the camera
  exposure was lowered to the reference value of 20 recorded in
  [`../config/camera_reference.json`](../config/camera_reference.json).
  Absolute brightness — and therefore absolute transmittance — is not
  comparable with runs captured after that change; the depth-resolved shape
  within this single run is what the example demonstrates.
- **Wavelengths are nominal.** 625 / 525 / 465 nm are the LED's rated
  values, not independently measured (±10–15 nm).
- **Geometry is auto-detected, not locked.** `geometry_locked` is `false`, so
  the meniscus/body/liquid-bottom rows come from per-run detection on the
  white reference rather than from a locked frame.

For the same reasons this single run is **not** offered as a comparison of
dispensing times: a dispensing-time series would have to be captured under
one fixed exposure and one locked frame, which this batch was not.

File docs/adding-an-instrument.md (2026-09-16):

# Adding a new instrument

This guide walks through adding an instrument that the flow executor can drive,
using a digital multimeter (DMM) as the running example. The same steps apply to
any instrument that does not belong to a particular robot arm: a pH meter, a
spectrometer, a second balance. Instruments mounted on an arm (a second pipette,
a gripper) go through `LabRobot` instead of `SharedDevices`; the layering is the
same, only the class differs.

The electronic balance is the closest existing example, and every step below
names the balance code to copy from. Read `src/devices/README.md` first for the
two-layer design (thin drivers, one safety wrapper).

## 0. Decide where it belongs

| Question | Answer for a DMM | Consequence |
|---|---|---|
| Is it attached to one robot arm? | No, it sits on the bench | Shared device: actions carry no `robot_id`, implemented in `SharedDevices` |
| Does a step produce a value worth recording? | Yes, a voltage | The step returns a result dict and the run log gets a new column |
| Does it move anything or dispense anything? | No | No workspace validation needed; nothing in `src/devices/safety/validators/` changes |

If the probe has to be positioned by the arm, keep the *measurement* a shared-device
action and express the positioning as ordinary `move_xyz` / `move_z` steps in the
flow. Do not add motion to a shared device.

## 1. Driver: `src/devices/<instrument>/`

Create `src/devices/dmm/` with `__init__.py`, a driver module and a short README
(command set, wiring, one usage example).

- Copy the shape of `SerialBalance` in `src/devices/scale/BCE8221.py`: a class that
  opens the connection in `__init__`, exposes a few instrument-level methods
  (`read_voltage()`, `read_current()`, ...) and a `close()`.
- The driver knows nothing about experiments, flows or robots.
- Every address (COM port, VISA resource string, Bluetooth address) is a
  constructor argument with a placeholder default. Never hard-code a real one.
- Use the protocol the instrument speaks. Most bench DMMs (Keysight, Keithley,
  Rigol) accept SCPI, e.g. `MEAS:VOLT:DC?`, over USB-TMC (`pyvisa`) or RS-232C /
  USB-CDC (`pyserial`). Add the library to `requirements.txt`, and if it is
  heavy or platform-specific, import it inside the driver module, not at package
  level, so the mock path never needs it (the balance does this with `serial`).
- Parse the reply into a `float` and return `None` when the reply is not a
  number, as `SerialBalance.get_weight()` does; the wrapper decides what to do
  with `None`.

## 2. Safety wrapper: `src/devices/safety/shared_devices.py`

Add the instrument to `SharedDevices` following the balance:

1. A `use_dmm: bool = False` constructor flag and `self.dmm = None`.
2. A settle time read from `device_configs` (`wait_after_dmm`, like `wait_after_scale`).
3. `_initialize_dmm()`: import the driver lazily, construct it from
   `device_configs['dmm_port']`, take one reading to prove the link, return
   `False` (with a logged error) on failure. Call it from `initialize()` when
   the flag is set.
4. The public async method the executor will call, e.g.
   `async def measure_voltage(self, samples: int = 3) -> float`. Take several
   readings and return the median, as `measure_weight()` does, then sleep the
   settle time. Raise, do not return `None`, when the instrument gives nothing
   usable; the executor records the exception per step.
5. Close the driver in `cleanup()`.

Do not touch `src/devices/safety/validators/` or the `workspace` section of
`config.yaml`; a measuring instrument has no business there.

## 3. Mock: `src/devices/safety/mock_robot.py`

`MockSharedDevices` must accept the same constructor flag and expose the same
method with the same signature. Return a fixed, plausible value
(`MOCK_VOLTAGE = 1.234`, next to `MOCK_WEIGHT`), never `None`: the mock run is
what tests, CI and `--mock` use to check that the value reaches the log.

## 4. Flow schema and executor

`src/flow/schema.py`

- Copy `ActionMeasureWeight` to `ActionMeasureVoltage` with
  `action: Literal["measure_voltage"]` and bounded parameters
  (`samples: int = Field(3, ge=1, le=10)`, range or function if the instrument
  needs them). Use `Field` bounds; they are the only validation a flow gets
  before it runs.
- Add the class to the `LabRobotAction` union. Only listed classes are valid steps.

`src/flow/executor.py`

- Add `"measure_voltage"` to `SHARED_DEVICE_ACTIONS` so the step is routed to
  the shared devices and is accepted without a `robot_id`.
- Add a branch in `execute_shared_device_step()` that reads the parameters from
  either a dict or the model (both forms reach it), calls the wrapper and
  returns `{"voltage": value}`.
- In `execute_workflow()`, derive `needs_dmm` from the actions present in the
  flow, next to `needs_scale` and `needs_camera`, and pass `use_dmm=needs_dmm`
  to `SharedDevices`. This is what lets a flow that never measures voltage run
  on a cell without a DMM.

`src/flow/experiment_logger.py`

- `record_step()` currently knows two result keys, `weight` and `image_path`,
  and writes them as the `weight_g` and `image_path` columns of `measurements.csv`.
  Add the new key the same way (`voltage_v`), and add the event kind to the
  time-line report if the value is worth listing there. If you expect more
  instruments, this is the moment to generalise to `measurement` / `unit`
  columns instead of one column per quantity.

## 5. Configuration

- `src/config.py`: add `dmm_port` to the `shared_devices` defaults.
- `config.example.yaml`: add the same key with a comment. `config.yaml` is
  gitignored; users copy the example.
- Optional: a `--dmm-port` argument and `DMM_PORT` environment variable in
  `src/flow/run_flow.py`, mirroring `--scale-port` / `SCALE_PORT`, so a port can
  be overridden per run without editing the file.

## 6. Tests

All tests run without hardware.

- Driver parsing: copy `tests/test_wp2_balance_sign.py`. Stub the serial or
  VISA module, build the driver with `object.__new__`, and check that the
  instrument's real reply strings (copy them from the manual or a terminal
  session) parse to the right number and that garbage gives `None`.
- End to end: add a flow containing `measure_voltage` to the mock-run test in
  `tests/test_run_flow.py` and assert that `measurements.csv` has the value in the new
  column. This catches a missing union entry, a missing action in
  `SHARED_DEVICE_ACTIONS`, and a mock that returns `None`.
- Run the full check before reporting done:

```bash
python -m pytest tests/ src/monitoring/tests/ -q
python -m src.flow.run_flow <your flow>.json --validate-only
python -m src.flow.run_flow <your flow>.json --mock
```

## 7. Documentation

- `docs/experimental-flow.md`: one row in the *Shared devices* table.
- `src/devices/README.md`: one row in the driver table and the method in the
  `SharedDevices` row.
- `docs/bom.md`: the instrument, with model and interface.
- `docs/setup.md`: how to connect it and find its port.
- `src/agent/llm_service.py`: the action list given to the flow-generating
  LLM. Add the action there if the agent should be able to use it; leave it out
  if it should not.

## Checklist

```
[ ] src/devices/<name>/            driver + README, addresses as arguments
[ ] shared_devices.py              flag, _initialize_*, async method, cleanup
[ ] mock_robot.py                  same method on MockSharedDevices, fixed value
[ ] schema.py                      Action* model, added to LabRobotAction
[ ] executor.py                    SHARED_DEVICE_ACTIONS, branch, needs_* flag
[ ] experiment_logger.py           result key -> CSV column
[ ] config.py + config.example.yaml   port key
[ ] tests/                         parser test + mock-run test
[ ] docs/experimental-flow.md, src/devices/README.md, docs/bom.md, docs/setup.md
[ ] pytest, --validate-only, --mock all green
```

## What not to do

- Do not make the executor call a driver directly. Every instrument goes
  through `SharedDevices` or `LabRobot`, so that the mock, the logging and the
  emergency stop cover it.
- Do not put a lab's port names, IP addresses or Bluetooth addresses in
  defaults, examples or tests.
- Do not add an instrument whose driver depends on an AGPL package under
  `src/`; `detection/` is kept separate for that reason.

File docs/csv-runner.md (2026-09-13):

# Spreadsheet (CSV) input — `src/flow/csv_runner`

The CSV runner is the shortest path from a spreadsheet to a run: the operator opens
one file in Excel, LibreOffice Calc or Numbers, types the volumes, heights, angles and
pipette speeds of a **two-solution mixing** experiment, saves, and runs one command.
No JSON is written by hand and no GUI is needed.

**This is the path used for the paper's ZIF-8 experiments.** The nine reported
batches were executed with the lab's version of this runner (internal
`excel_runner/run_csv.py`, commit `4584333`, in force from 2026-07-02), not with
hand-written or LLM-generated JSON. The runner published here reproduces that
sequence step for step.

The experiment itself is fixed. The runner always performs the same ten steps per
robot, Robot 1 first and then Robot 2, and only substitutes the numbers from the CSV:

    for each robot (1, then 2), if its volume is not 0:
        1  move_z(-aspirate_z_descent_mm)     lower onto its source vessel
        2  aspirate                           (robot*_volume_mL, aspirate_speed)
        3  move_z(+aspirate_z_descent_mm)     rise
        4  rotate_relative(angle, "low")      swing over the vial on the balance
        5  move_z(-dispense_z_descent_mm)     lower into the vial
        6  tare_scale(delay=1.0)              tare with the tip already lowered
        7  dispense                           (robot*_volume_mL, robot*_dispense_speed)
        8  measure_weight                     read the mass BEFORE the tip rises
        9  move_z(+dispense_z_descent_mm)     rise
       10  go_home                            the home move also undoes the rotation

    once, only if capture_photo is TRUE:
        capture_and_save                      photograph the vial
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

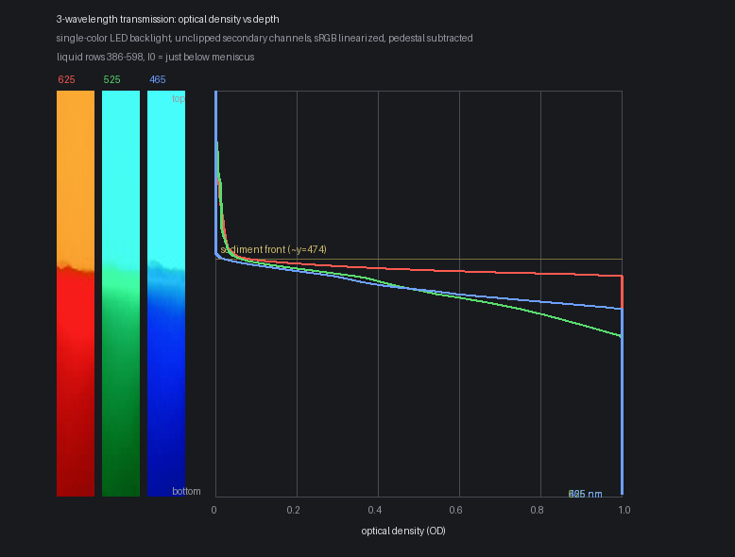
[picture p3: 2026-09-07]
src/imaging/examples/zif8_vial_5s/spectral.png

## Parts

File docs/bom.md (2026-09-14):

# Bill of Materials (BOM)

Hardware used in the reference implementation described in the paper. Equivalent
instruments can be substituted; the control drivers in `src/devices/` are written
per-device and can be adapted.

## Instruments

| Item | Model | Qty | Notes |
|---|---|---|---|
| Hot-plate stirrer | IKA RET control-visc | 2 | RT–340 °C, 50–1700 rpm, RS-232/USB. Only stirring and temperature control are used; see the note below before buying this model |
| Robot arm | Dobot Magician | 2 | One per solution to prevent cross-contamination |
| Electric pipette | Sartorius Picus 2 (500–10,000 μL) | 2 | Dispensing speed electronically controlled in 9 steps, about 1–11 mL/s (nominal) |
| Electronic balance | Sartorius BCE822i-1SJP | 1 | Capacity 820 g, readability 0.01 g |
| Web camera (process monitoring) | Logitech C920n | 1 | Fixed above the system |
| Web camera (appearance imaging) | Logitech C920n | 1 | Part of the imaging system (`src/imaging/`) |
| Light | NEEWER RGB62 | 1 | White/red/green/blue illumination, controlled over Bluetooth LE (`src/imaging/`) |
| IoT sensor board | Raspberry Pi Zero WH + Waveshare Environment Sensor HAT | 1 | Temperature, humidity, illuminance, UV, VOC, 3-axis acceleration and angular velocity (magnetometer not read; see `src/monitoring/README.md`) |
| Control PC | — | 1 | Connects to all devices via Wi-Fi or USB |

**Note on the hot-plate stirrer.** The RET control-visc has a built-in weighing
function, but it is of no use for this platform: IKA specifies a weighing range of
10–5000 g with an accuracy of ±(0.3 % + 2) g, so a 5 g dispense would carry an
uncertainty of about ±2 g. All mass measurements in SAIGEN are therefore
made with the electronic balance, and the driver in `src/devices/ika/` only uses the
stirring and temperature commands (IKA NAMUR command set over RS-232/USB). Any IKA
plate with that interface is sufficient; the **IKA Plate (RCT digital)** (RT–310 °C,
50–1500 rpm, RS-232 and USB, same NAMUR commands) is the cheaper choice we would
recommend for a new build. Japanese list prices on ika.com in September 2026:
RET control-visc JPY 298,000, IKA Plate (RCT digital) JPY 184,000. We have not yet
run the driver against an RCT digital ourselves; the commands it sends
(`OUT_SP_2`, `OUT_SP_4`, `START_2/4`, `STOP_2/4`, `IN_PV_x`) are documented for both
models, but confirm on your unit with `--mock` first and then a short real test.

## Fabrication

| Item | Model | Notes |
|---|---|---|
| 3D printer | Bambu Lab X1E | Used to print all fixtures in `cad/` |
| CAD software | Autodesk Fusion 360 | Source `.f3d` / `.f3z` files provided in `cad/` |

## Software / AI services

| Component | Used in |
|---|---|
| Gemini 3.5 Flash (Google) | `src/agent/` — control-code and experimental-flow generation |
| whisper-large-v3-turbo (OpenAI) | `src/voice/` — speech-to-text for voice input |
| YOLOv8 (Ultralytics, AGPL-3.0) | `detection/` — optional object detection for process monitoring |

<!-- TODO: add 3D-printing filament type/settings and any wiring or adapters used. -->

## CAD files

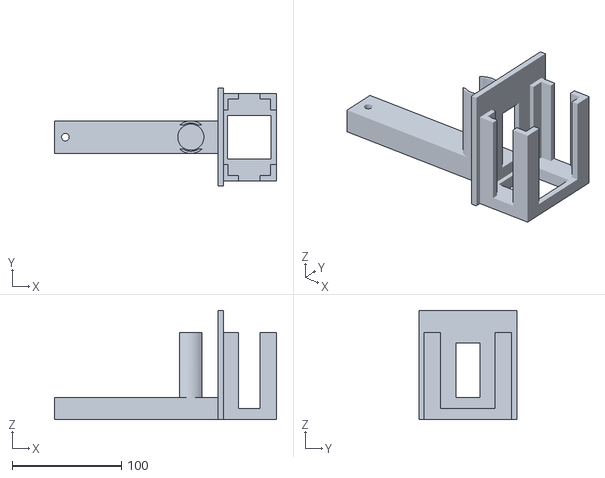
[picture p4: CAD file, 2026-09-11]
cad/imaging-stand/imaging_stand_assembly.stl
203.5 x 90.0 x 100.0

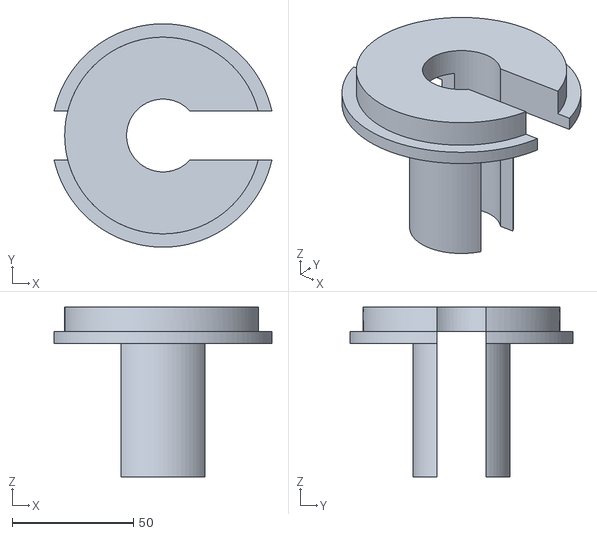
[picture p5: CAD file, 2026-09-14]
cad/balance-cover/adapters/tube_adapter_centrifuge_50ml.stl
89.8 x 92.0 x 70.0

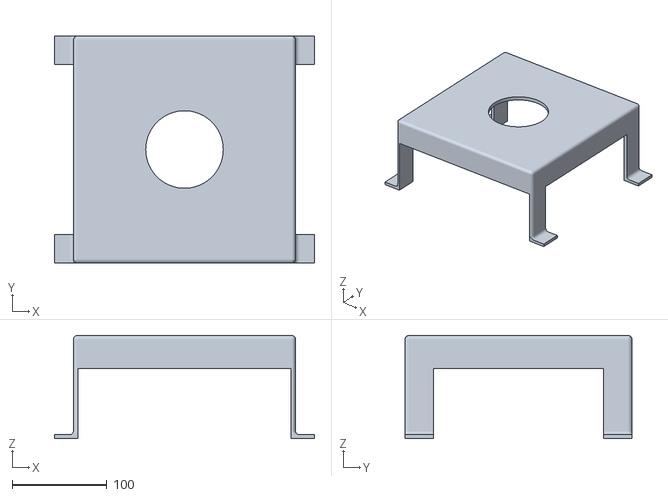
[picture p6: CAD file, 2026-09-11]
cad/balance-cover/balance_cover_bce822i.stl
275.0 x 240.0 x 109.0

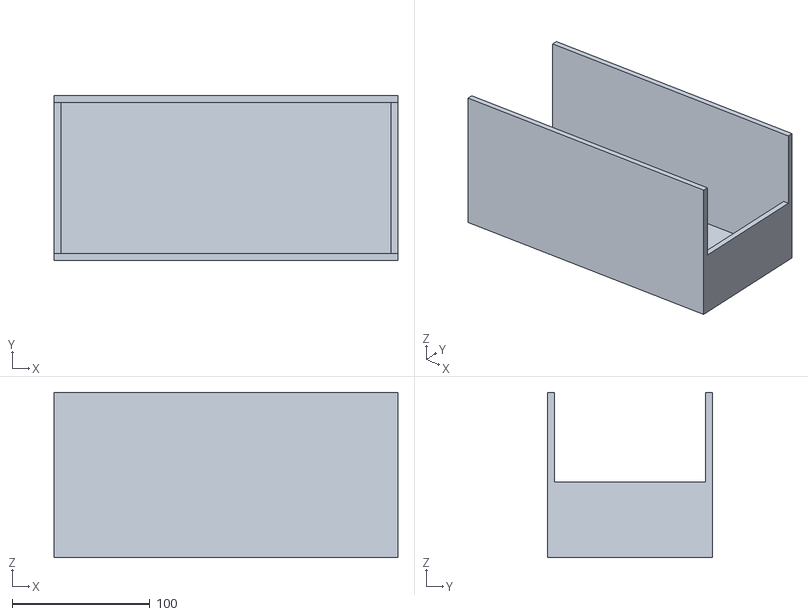
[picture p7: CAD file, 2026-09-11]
cad/imaging-stand/imaging_stand_light_shield.stl
250.0 x 120.0 x 120.0

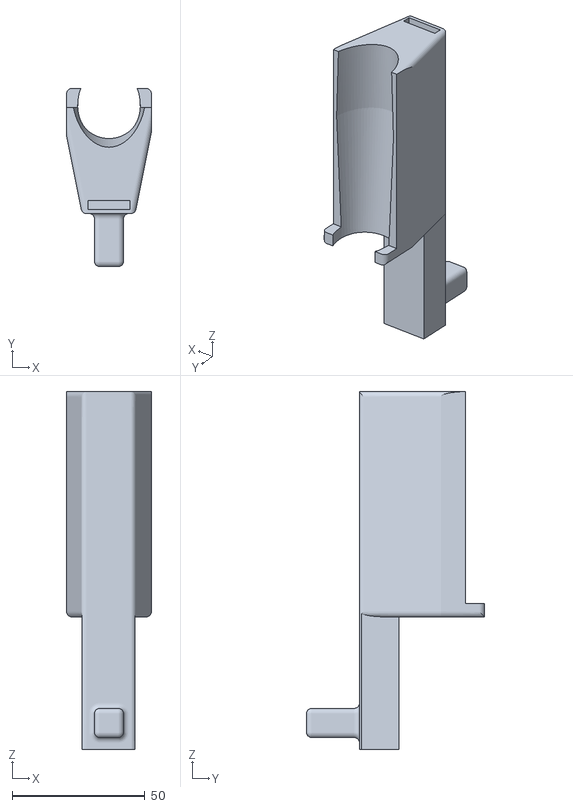
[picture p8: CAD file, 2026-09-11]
cad/pipette-holder/picus2_holder.stl
32.0 x 67.2 x 135.0

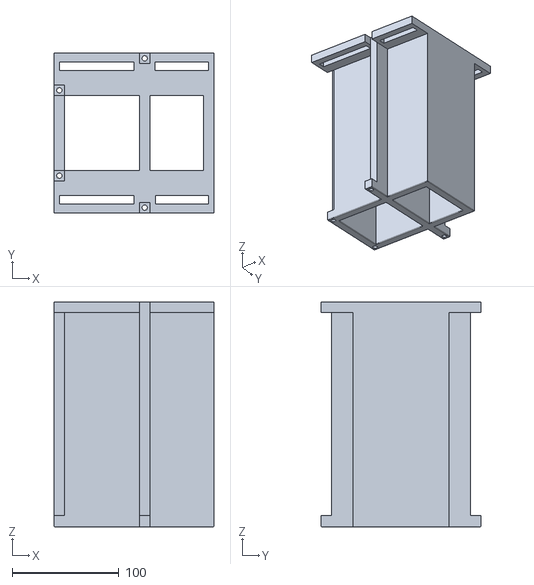
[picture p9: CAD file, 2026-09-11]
cad/robot-arm-holder/dobot_magician_holder_210mm.stl
150.0 x 150.0 x 211.0

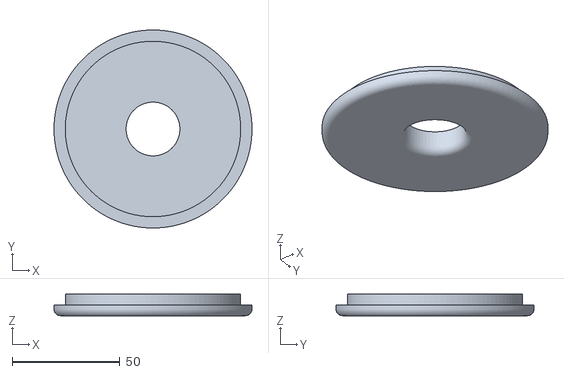
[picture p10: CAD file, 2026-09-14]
cad/balance-cover/adapters/vial_adapter_screw_no4.stl
92.0 x 92.0 x 10.0

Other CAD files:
cad/balance-cover/adapters/tube_adapter_centrifuge_50ml.f3d
cad/balance-cover/adapters/vial_adapter_screw_no4.f3d
cad/balance-cover/balance_cover_bce822i.f3d
cad/imaging-stand/imaging_stand_assembly.f3z
cad/imaging-stand/imaging_stand_light_shield.f3d
cad/pipette-holder/picus2_holder.f3d
cad/robot-arm-holder/dobot_magician_holder_210mm.f3d

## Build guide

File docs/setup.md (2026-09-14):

# Setup guide

From an empty control PC to the first automated dispense. Windows 11 is the
reference platform (the pipette and balance drivers use COM ports); the flow
executor, agent, GUI and voice input also run on macOS/Linux with `/dev/tty*`
device names.

## 1. Hardware

See [`bom.md`](bom.md) for the full list. The minimum for the ZIF-8 demonstration:

- 2 × robot arm (Dobot Magician), USB
- 2 × electric pipette (Sartorius Picus 2, 10 mL), USB (Bluetooth is also supported)
- 1 × electronic balance (Sartorius BCE822i) with RS-232C/USB serial
- 2 × hot-plate stirrer (IKA RET control-visc, or a cheaper IKA plate with the same
  NAMUR serial interface such as the IKA Plate (RCT digital); see `bom.md`) — optional, RS-232C/USB
- 1 × USB webcam
- 3D-printed fixtures from `cad/` (pipette holders on the arm tips, flask holders,
  balance splash guard)

Assembly: mount one pipette on each arm, place the receiving vial on the balance
between the arms, put each solution flask on its stirrer within reach of the
corresponding arm. **One arm + one pipette per solution**, so tips are never
exchanged.

Connect everything to the control PC and note the port of each device
(Windows: Device Manager → *Ports (COM & LPT)*; unplug/replug to identify).

## 2. Software

```bash
git clone https://github.com/YusukeHashimotoLab/saigen.git
cd saigen
python -m venv venv
# Windows
venv\Scripts\activate
# macOS / Linux
source venv/bin/activate
pip install -r requirements.txt
```

Python 3.11–3.13. Optional extras:

- `ffmpeg` on PATH for voice input (`winget install ffmpeg` / `brew install ffmpeg`).
- A CUDA GPU speeds up whisper; CPU works with the int8 model.

## 3. Configuration (`config.yaml` and `.env`)

Two files, with different jobs: `config.yaml` holds the ports and the workspace
limits of your cell; `.env` holds API keys and per-run overrides. Both are
git-ignored.

```bash
cp config.example.yaml config.yaml
cp .env.example .env
```

Edit `config.yaml`:

| Section | Purpose |
|---|---|
| `robots` | `dobot_port` (and `picus2_address`, if that robot has a pipette) per `robot_id` |
| `shared_devices` | `scale_port` and `camera_index` of the balance and the photo camera |
| `workspace` | X/Y/Z and Joint-1 limits every move is checked against before it is commanded |

If `config.yaml` is absent the tracked `config.example.yaml` is used, and if that is
absent too the built-in defaults in `src/config.py` apply. Sensor-dashboard ports and
the video-recording camera index live in `src/monitoring/config.yaml` (section 8).

Edit `.env`:

| Variable | Purpose |
|---|---|
| `LLM_MODE` | `gemini` (default) or `openai_compatible` |
| `GEMINI_API_KEY` | required for `gemini`; free key from Google AI Studio |
| `LLM_BASE_URL`, `LLM_API_KEY`, `LLM_MODEL` | for any OpenAI-compatible endpoint (local inference server etc.) |
| `ROBOT1_DOBOT_PORT`, `ROBOT1_PICUS2_PORT`, `ROBOT2_*`, `ROBOT3_DOBOT_PORT` | optional per-run override of the `config.yaml` robot ports |
| `SCALE_PORT`, `CAMERA_INDEX` | optional per-run override of the shared devices |
| `SENSOR_SERVER_URL` | dashboard URL used to start/stop recording (optional) |

`.env` is git-ignored. No key is read from anywhere else. For device ports the
resolution order is: command-line flag > `.env` > `config.yaml` > built-in defaults.

## 4. Check the devices one by one

Each driver has a small self-test; run them with the arm clear of obstacles.

```bash
python -m src.devices.dobot.pydobot_controller          # lists serial ports, connects, reads position
python src/devices/picus2/test_picus2_minimal.py         # edit the port inside the file first
python -m src.devices.scale.scale_controller             # reads the balance
```

For the arm, confirm the `workspace` section of `config.yaml` matches your fixtures
before running any flow: every `move_xyz` / `move_z` / `rotate` target is checked
against those limits **before** the robot is commanded, and a violation aborts the
run. The check also runs in `--mock` mode, so you can screen a flow for
out-of-range moves without hardware.

## 5. First run without hardware

```bash
python -m src.flow.run_flow examples/zif8/zif8_two_solution_mixing_speed5.json --validate-only
python -m src.flow.run_flow examples/zif8/zif8_two_solution_mixing_speed5.json --mock
```

`--validate-only` checks the JSON against the schema and expands loops.
`--mock` runs the whole flow against simulated robots and logs every action; the
workspace limits are enforced, and recording is always off. A mock run produces the
same `logs/<date>/<flow name>_<timestamp>/` folder as a real one, so you can inspect
`run.log`, `measurements.csv`, `summary.md` and `metadata.json` before touching
hardware.

Run the test suite too — it needs no hardware:

```bash
pytest tests/
```

## 6. First run with hardware

1. Move each arm by hand (or with the driver self-test) to the pose you want as
   *home*: pipette tip above the flask, clear of everything. The runner captures the
   current pose as home at start-up; `go_home` returns there.
2. Check the reach: run the position-check presets (`src/agent/presets/wdc_2_dispense_robot1.json`
   etc.) — they move without aspirating.
3. Run the flow:

```bash
python -m src.flow.run_flow examples/zif8/zif8_two_solution_mixing_speed5.json \
    --robot1-dobot COM12 --robot1-picus2 COM4 \
    --robot2-dobot COM7  --robot2-picus2 COM5 \
    --scale-port COM9 --camera-index 1
```

Flags override `.env`, which overrides `config.yaml`. Only the robots referenced by
`robot_id` in the flow are initialised.

Press Ctrl+C to stop: this is an **emergency stop** — the Dobot command queue is
force-stopped so the move in progress halts immediately, the queue is discarded, the
conveyor motors and the IKA heater/stirrer are switched off, and no further motion
(not even going home) is commanded before the devices are disconnected.

Every run writes `logs/<YYYY-MM-DD>/<flow name>_<timestamp>/` containing `run.log`,
`measurements.csv` (one row per step, with the weights and image paths),
`summary.md`, `metadata.json`, `images/` and a copy of the flow JSON. Real runs also
record sensor CSV and overhead video by default; pass `--no-record` to skip that.

For the two-solution mixing experiment the parameters can be entered in a spreadsheet
instead of a JSON flow:

```bash
cp src/flow/csv_runner/control.example.csv src/flow/csv_runner/control.csv
python -m src.flow.csv_runner.run_csv --mock     # then without --mock
```

Same validation, same safety frame, same `logs/<date>/…` folder; the dispensed masses
are also written back to `results.csv` next to the sheet. See [`csv-runner.md`](csv-runner.md).

## 7. GUI and the AI agent

```bash
streamlit run src/gui/app.py
```

The browser opens at `http://localhost:8501`. In the sidebar set the ports and
toggle *Mock* on for a dry run. Then either

- pick a preset and press *Run*, or
- describe the experiment in natural language (typed, or spoken with the microphone
  button), let the agent produce the JSON flow, review and edit it in the step
  editor, and press *Run*.

The ports shown in the sidebar are read from `config.yaml` (see §3); edits there apply
to the current browser session only. Pressing *Run* first validates the flow against
`src/flow/schema.py` — a flow that fails is refused and the offending steps are listed,
so nothing is sent to the instruments. The run then goes through the same
`ExperimentSession` as the CLI and produces the same `logs/<date>/<flow>_<timestamp>/`
folder (`run.log`, `measurements.csv`, `dispense_accuracy.csv`, `metadata.json`,
`summary.md`, `images/`), whose path is shown under the progress bar. *Stop* cancels the
run, emergency-stops every robot and disconnects them. In Real mode, if the monitoring
dashboard is running, sensor recording is started and stopped around the run and its
`/api/is_safe` check gates each step. For the statistics of a dispensing run:

```bash
python -m src.gui.analyze_dispense_log logs/<date>/<flow>_<timestamp>
```

## 8. Monitoring (optional)

```bash
pip install -r src/monitoring/requirements.txt
cp src/monitoring/config.example.yaml src/monitoring/config.yaml
python src/monitoring/dashboard/launch_sensor_dashboard.py
```

opens the dashboard at `http://localhost:8000`, receives sensor data from Raspberry Pi
agents over TCP and records CSV/video into `experiment_data/`. Installing the Pi agent
and the network settings are described in `src/monitoring/README.md`.

## Troubleshooting

- **`GEMINI_API_KEY が設定されていません`** — the key is missing from `.env`, or the
  process was started from another directory (`.env` is loaded from the current
  working directory).
- **Pipette does not connect** — the Picus 2 must be switched on and in remote mode;
  the wrapper retries three times. On Bluetooth, pass the MAC address instead of a
  COM port and set `picus2_connection_type="bluetooth"`.
- **`WorkspaceViolationError`** — the target is outside the configured box; adjust the
  flow, or the `workspace` section of `config.yaml`. The message names the axis, the
  target value and the limit it broke.
- **Camera index** — enumeration order differs between machines; try 0, 1, 2.

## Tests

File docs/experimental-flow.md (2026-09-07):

# Experimental flow format

The AI agent outputs experimental procedures as a JSON "experimental flow" — an
intermediate representation connecting the natural-language experimental objective
with the control code actually executed. Constraining the LLM output to structured
JSON suppresses generation variability and enables mechanical validation before
execution.

The schema is defined with Pydantic in [`src/flow/schema.py`](../src/flow/schema.py)
and executed by [`src/flow/executor.py`](../src/flow/executor.py). Run
`python src/flow/schema.py` to print the machine-readable JSON Schema.

## Top level

```json
{
  "name": "human-readable name",
  "description": "what the flow does",
  "steps": [ { "action": "...", ... }, ... ]
}
```

| Field | Type | Required | Notes |
|---|---|---|---|
| `name` | string | yes | |
| `description` | string | no | default `""` |
| `steps` | array | yes | executed in order; each element is one of the actions below |

Every step has an `action` field. Robot actions take `robot_id` (1–3, default 1);
shared-device actions (balance, camera) do not. Unknown fields or out-of-range values
are rejected at validation time.

## Actions

### Robot arm (Dobot Magician) — `robot_id` required

| `action` | Parameters | Description |
|---|---|---|
| `move_xyz` | `x`, `y`, `z` (mm) | Absolute move in the arm's Cartesian frame |
| `move_z` | `distance` (mm) | Relative vertical move; positive = up |
| `move_radial` | `distance` (mm) | Relative move along the radius from the base; positive = outward |
| `rotate` | `angle` (deg) | Absolute base (joint 1) rotation |
| `rotate_relative` | `angle` (deg), `speed` (`"low"`/`"normal"`/`"high"`, default `"low"`) | Relative base rotation; positive = counter-clockwise seen from above (toward +Y) |
| `go_home` | — | Return to the home position captured at start-up |
| `move_slider` | `position` (0–1000 mm) | Linear rail (optional accessory) |
| `move_conveyer` | `index` (0/1), `speed` (0–200 mm/s), `duration` (0–300 s) | Conveyor belt (optional accessory) |

### Electric pipette (Sartorius Picus 2) — `robot_id` required

| `action` | Parameters | Description |
|---|---|---|
| `aspirate` | `volume` (0 < v ≤ 10 mL), `speed` (1–9, default 5) | Aspirate; the wrapper refuses to exceed 10 mL total |
| `dispense` | `volume` (0 < v ≤ 10 mL), `speed` (1–9, default 5) | Dispense; refuses to exceed the held volume |
| `blow_out` | `go_home` (bool, default true), `speed` (1–9, default 1), `delay_ms` (int, default 3000) | Expel residual liquid |

Speed 1 is slowest, 9 fastest (about 1–11 mL/s for a 10 mL tip, from the manufacturer's timing table).

### Shared devices — no `robot_id`

| `action` | Parameters | Description |
|---|---|---|
| `tare_scale` | `delay` (0.1–10 s, default 1.0) | Tare the electronic balance |
| `measure_weight` | `stabilization_count` (1–10, default 3) | Read the balance; median of N readings, logged in grams |
| `capture_and_save` | `file_path` (string, `""` = auto-generate) | Capture a webcam image |

### Utility and control flow

| `action` | Parameters | Description |
|---|---|---|
| `wait` | `seconds` (≥ 0) | Sleep |
| `loop_start` | `loop_id` (string), `count` (1–1000) | Begin a loop |
| `loop_end` | `loop_id` | End the loop with the same `loop_id` |

Loops are expanded into a flat list before execution (`expand_loops`). Nesting is not
supported; a `loop_start` without a matching `loop_end` (or vice versa) is an error.

## Validation rules

Applied before any device moves:

1. **Schema** — every step must match exactly one action model; types and ranges
   above are enforced by Pydantic.
2. **Loop structure** — `loop_id`s must pair up and must not nest.
3. **Pipette volume tracking** (run time, in the safety wrapper) — cumulative
   `aspirate` may not exceed 10 mL; `dispense` may not exceed the volume held.
4. **Workspace limits** (run time) — `move_xyz` / `move_z` / `rotate*` targets are
   checked against the XYZ box and joint-1 range in the `workspace` section of
   `config.yaml`; a violation raises before the command is sent, aborting the run.
   The same check runs in `--mock` mode, so a flow can be screened for out-of-range
   moves without hardware.

Conventions the agent's system prompt also enforces: Robot 3 (rail robot) carries
no pipette; each loop body and the whole flow end with `go_home`.

## Full example — ZIF-8 two-solution mixing

This is `examples/zif8/zif8_two_solution_mixing_speed5.json` (solution 2 dispensed at
pipette speed 5, nominal ≈1.45 s for 5 mL). The `speed1` and `speed9` variants differ
only in the `speed` of the second `dispense`.

The three files are the **JSON equivalents of the CSV-runner sequence** — the fixed
ten-step-per-robot sequence in [`docs/csv-runner.md`](csv-runner.md) that the paper's
ZIF-8 batches were actually run with — plus one closing `capture_and_save`, which the
CSV runs did not take. They are not the files that were executed for the paper; see
`examples/zif8/README.md`.

Running a flow leaves a record of the run in
`logs/<YYYY-MM-DD>/<flow name>_<timestamp>/`: `run.log`, `measurements.csv` (one row
per step, with the weights read, the nominal pipette duration of each aspirate/dispense
step from the Picus 2 timing table, and the photographs taken), `summary.md`,
`metadata.json`, `images/` and a copy of the flow JSON. See
[`src/flow/README.md`](../src/flow/README.md).

```json
{
  "name": "ZIF-8 two-solution mixing (solution 2 dispensed at pipette speed 5)",
  "description": "… (see the file)",
  "steps": [
    {"action": "move_z", "robot_id": 1, "distance": -0.1},
    {"action": "aspirate", "robot_id": 1, "volume": 5.0, "speed": 1},
    {"action": "move_z", "robot_id": 1, "distance": 0.1},
    {"action": "rotate_relative", "robot_id": 1, "angle": 90.0, "speed": "low"},
    {"action": "move_z", "robot_id": 1, "distance": -120.0},
    {"action": "tare_scale", "delay": 1.0},
    {"action": "dispense", "robot_id": 1, "volume": 5.0, "speed": 9},
    {"action": "measure_weight", "stabilization_count": 3},
    {"action": "move_z", "robot_id": 1, "distance": 120.0},
    {"action": "go_home", "robot_id": 1},

    {"action": "move_z", "robot_id": 2, "distance": -0.1},
    {"action": "aspirate", "robot_id": 2, "volume": 5.0, "speed": 1},
    {"action": "move_z", "robot_id": 2, "distance": 0.1},
    {"action": "rotate_relative", "robot_id": 2, "angle": -90.0, "speed": "low"},
    {"action": "move_z", "robot_id": 2, "distance": -120.0},
    {"action": "tare_scale", "delay": 1.0},
    {"action": "dispense", "robot_id": 2, "volume": 5.0, "speed": 5},
    {"action": "measure_weight", "stabilization_count": 3},
    {"action": "move_z", "robot_id": 2, "distance": 120.0},
    {"action": "go_home", "robot_id": 2},

    {"action": "capture_and_save", "file_path": ""}
  ]
}
```

Note the order inside each robot's block: the balance is tared only after the tip is
down in the vial, the mass is read before the tip rises again, and `go_home` — not a
second `rotate_relative` — brings the arm back.

Distances and angles are specific to the fixture geometry; see
`examples/zif8/README.md` for how to adapt them.

## Presets

Flows that have been checked on hardware are stored as *presets* in
`src/agent/presets/*.json`. A preset wraps a flow in `{"label", "description",
"template"}` and is offered in the GUI; the agent can also be asked to change only
the parameters of a preset (the step order is kept), which is the recommended way to
derive a new condition from a validated procedure.

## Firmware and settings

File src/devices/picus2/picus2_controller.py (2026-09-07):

"""
Picus2電動ピペットを制御するためのモジュール

このモジュールはPicus2電子ピペットをUSBまたはBluetooth経由で操作するためのインターフェースを提供します。
液体の吸引、吐出、チップの排出、混合など、実験自動化に必要な機能をサポートしています。

使用方法:
    import asyncio
    from picus2.picus2_controller import Picus2Controller, Buttons, ConnectionType

    async def run_demo():
        # USB接続の場合（デフォルト）
        picus = Picus2Controller("COM4")  # または Picus2Controller("COM4", connection_type=ConnectionType.USB)

        # Bluetooth接続の場合
        # picus = Picus2Controller("XX:XX:XX:XX:XX:XX", connection_type=ConnectionType.BLUETOOTH)

        # 接続
        await picus.connect()

        # モーターモードを有効化
        await picus.set_motor_mode(True)

        # 5mLを吸引
        await picus.aspirate(5.0, speed=5)

        # 5mLを吐出
        await picus.dispense(5.0, speed=5)

        # 切断
        await picus.disconnect()

    # 非同期関数を実行
    asyncio.run(run_demo())

"""

import asyncio
import json
import logging
import time
from enum import Enum
from typing import Optional

try:  # ハードウェア依存ライブラリは未インストール環境でも import を通す
    import serial
except ImportError:  # pragma: no cover - 実機環境では常に成功する
    serial = None

try:
    from bleak import BleakClient
except ImportError:  # pragma: no cover
    BleakClient = None

logger = logging.getLogger(__name__)

# 速度ごとの 10000μL 当たりの所要時間(秒)。Picus2 マニュアル 63 ページの表。
SECONDS_PER_10000UL = {
    1: 10.2,
    2: 7.4,
    3: 5.4,
    4: 3.8,
    5: 2.9,
    6: 2.2,
    7: 1.7,
    8: 1.3,
    9: 0.9,
}


def nominal_operation_time(amount: float, speed: int) -> float:
    """吸引/吐出の公称所要時間(秒)を返す（マニュアル p.63 の表より）。

    Args:
        amount (float): 量 (mL)
        speed (int): 速度 (1-9)

    Returns:
        float: 公称所要時間 (s)。例: 5.0 mL / speed 5 → 1.45 s
    """
    if speed not in SECONDS_PER_10000UL:
        raise ValueError(f"speedは1-9の範囲で指定してください（指定値: {speed}）")
    return amount * SECONDS_PER_10000UL[speed] / 10


class ConnectionType(Enum):
    """接続タイプを表す列挙型"""
    USB = "usb"
    BLUETOOTH = "bluetooth"


class Buttons:
    """ピペットのボタン種類を表す定数クラス"""

    # 電源ボタン
    TRIGGER_BUTTON_POWER = "TRIGGER_BUTTON_POWER"
    # 左ボタン
    TRIGGER_BUTTON_LEFT = "TRIGGER_BUTTON_LEFT"
    # 中央ボタン
    TRIGGER_BUTTON_MIDDLE = "TRIGGER_BUTTON_MIDDLE"
    # 右ボタン
    TRIGGER_BUTTON_RIGHT = "TRIGGER_BUTTON_RIGHT"
    # 上部トリガーボタン
    TRIGGER_BUTTON_TOP = "TRIGGER_BUTTON_TOP"
    # プリセットボタン
    TRIGGER_BUTTON_PRESET = "TRIGGER_BUTTON_PRESET"
    # チップ排出ボタン
    TRIGGER_BUTTON_TIPEJECT = "TRIGGER_BUTTON_TIPEJECT"
    # 上方向ボタン
    UP = "UP"
    # 下方向ボタン
    DOWN = "DOWN"


class Picus2Controller:
    """Picus2電動ピペットを操作するクラス"""

    def __init__(self, address: str, connection_type: ConnectionType = ConnectionType.USB):
        """
        Picus2コントローラーを初期化する

        Args:
            address (str): USB接続の場合はCOMポート（例: "COM4"）、
                          Bluetooth接続の場合はMACアドレス（例: "XX:XX:XX:XX:XX:XX"）
            connection_type (ConnectionType): 接続タイプ。デフォルトはUSB
        """
        self.address = address
        self.connection_type = connection_type
        self.motor_mode = False
        self.end_flag = False
        self.DEBUG = False

        # Bluetooth用
        self.client: Optional["BleakClient"] = None
        self.COMMAND_CHARACTERISTIC_UUID = "6e400002-b5a3-f393-e0a9-e50e24dcca9e"
        self.NOTIFY_CHARACTERISTIC_UUID = "6e400003-b5a3-f393-e0a9-e50e24dcca9e"

        # USB用
        self.serial: Optional["serial.Serial"] = None

    @property
    def is_connected(self) -> bool:
        """接続中かどうか（USB/Bluetooth 共通）"""
        if self.connection_type == ConnectionType.USB:
            return self.serial is not None and bool(getattr(self.serial, "is_open", False))
        return self.client is not None and bool(getattr(self.client, "is_connected", False))

    def _require_connection(self):
        """未接続の場合は例外を送出する。

        以前は未接続でもコマンド送信が黙って無視され、実際には何も動いていない
        まま処理が進む危険があった（Dobot ドライバの ``_require_device()`` と同じ方針）。
        """
        if not self.is_connected:
            raise ConnectionError(
                f"Picus2 が接続されていません (address={self.address}, "
                f"type={self.connection_type.value})。操作を中止します。"
            )

    async def connect(self) -> bool:
        """
        Picus2に接続する

        Returns:
            bool: 接続に成功した場合 True

        Raises:
            ConnectionError: 接続に失敗した場合（ポート名と元例外を含む）
        """
        if self.connection_type == ConnectionType.USB:
            return await self._connect_usb()
        else:
            return await self._connect_bluetooth()

    async def _connect_usb(self) -> bool:
        """USB経由でPicus2に接続する（失敗時は ConnectionError）"""
        if serial is None:
            raise ConnectionError(
                f"pyserial がインストールされていないため Picus2 に接続できません "
                f"(port={self.address})"
            )
        try:
            self.serial = serial.Serial(
                port=self.address,
                baudrate=230400,
                bytesize=8,
                parity="N",
                stopbits=1,
                timeout=1.0,
            )
        except Exception as e:
            self.serial = None
            self.debug_print(f"USB接続エラー: {e}")
            raise ConnectionError(
                f"Picus2 のUSB接続に失敗しました (port={self.address}): {e}"
            ) from e

        if not getattr(self.serial, "is_open", False):
            self.serial = None
            raise ConnectionError(
                f"Picus2 のUSBポートを開けませんでした (port={self.address})"
            )

        self.debug_print(f"USB接続状態: True")
        return True

    async def _connect_bluetooth(self) -> bool:
        """Bluetooth経由でPicus2に接続する（失敗時は ConnectionError）"""
        if BleakClient is None:
            raise ConnectionError(
                f"bleak がインストールされていないため Picus2 に接続できません "
                f"(address={self.address})"
            )
        try:
            self.client = BleakClient(self.address)
            await self.client.connect()
            is_connected = self.client.is_connected
            await asyncio.sleep(1)  # 早すぎるとエラーになるため少し待機

            if not is_connected:
                raise ConnectionError("BleakClient.is_connected が False です")

            # 通知の設定
            await self.client.start_notify(
                self.NOTIFY_CHARACTERISTIC_UUID, self.__notification_handler
            )
        except ConnectionError:
            self.client = None
            raise
        except Exception as e:
            self.client = None
            self.debug_print(f"Bluetooth接続エラー: {e}")
            raise ConnectionError(
                f"Picus2 のBluetooth接続に失敗しました (address={self.address}): {e}"
            ) from e

        self.debug_print(f"Bluetooth接続状態: True")
        return True

    async def disconnect(self):
        """
        Picus2から切断する

        Returns:
            bool: 切断が成功したかどうか
        """
        if self.connection_type == ConnectionType.USB:
            return await self._disconnect_usb()
        else:
            return await self._disconnect_bluetooth()

    async def _disconnect_usb(self):
        """USB接続を切断する"""
        if self.serial and self.serial.is_open:
            self.serial.close()
        is_disconnected = self.serial is None or not self.serial.is_open
        self.debug_print(f"USB切断状態: {is_disconnected}")
        return is_disconnected

    async def _disconnect_bluetooth(self):
        """Bluetooth接続を切断する"""
        if self.client:
            await self.client.disconnect()
            is_connected = self.client.is_connected
            self.debug_print(f"Bluetooth切断状態: {not is_connected}")
            return not is_connected
        return True

    async def send_command(self, command: str):
        """
        コマンドを送信する

        Args:
            command (str): 送信するコマンド
        """
        self.debug_print(f"送信: {command}")
        if self.connection_type == ConnectionType.USB:
            await self._send_command_usb(command)
        else:
            await self._send_command_bluetooth(command)

    async def _send_command_usb(self, command: str):
        """USB経由でコマンドを送信する"""
        if self.serial and self.serial.is_open:
            self.serial.flush()
            self.serial.write(f"{command}\r\n".encode("utf-8"))

    async def _send_command_bluetooth(self, command: str):
        """Bluetooth経由でコマンドを送信する"""
        if self.client:
            write_value = bytearray(f"{command}\r\n", "utf-8")
            await self.client.write_gatt_char(self.COMMAND_CHARACTERISTIC_UUID, write_value)

    async def __notification_handler(self, sender, data: bytearray):
        """
        Bluetooth通知を受信したときの処理

        Args:
            sender: 送信元
            data (bytearray): 受信したデータ
        """
        if self.DEBUG:
            self.debug_print(f"受信: {data}")
        data_str = data.decode("utf-8")
        if data_str.startswith("END"):
            self.end_flag = True
            self.debug_print(f"self.end_flag = True!")
        self.debug_print(self.end_flag)

    async def wait_until_END_received(self, timeout: float = 10):
        """ENDが受信されるまで待機する"""
        if self.connection_type == ConnectionType.USB:
            await self._wait_for_response_usb("END", timeout)
        else:
            await self._wait_for_response_bluetooth()

    async def _wait_for_response_usb(self, target_prefix: str, timeout: float = 10):
        """USB経由でレスポンスを待機する"""
        start_time = time.time()
        while True:
            if self.serial and self.serial.is_open:
                line = self.serial.readline().decode("utf-8").strip()
                if line:
                    self.debug_print(f"USB受信: {line}")
                if line.startswith(target_prefix):
                    self.debug_print(f"目標レスポンス受信: {line}")
                    break
            if time.time() - start_time > timeout:
                raise TimeoutError(f"Timeout waiting for response: {target_prefix}")
            await asyncio.sleep(0.01)

    async def _wait_for_response_bluetooth(self):
        """Bluetooth経由でENDレスポンスを待機する"""
        while not self.end_flag:
            self.debug_print(f"待機中...: {self.end_flag}")
            await asyncio.sleep(0.1)
        self.end_flag = False
        self.debug_print(f"END受信完了! {self.end_flag}")

    def calculate_operation_time(self, amount: float, speed: int) -> float:
        """
        ピペット操作にかかる時間を計算する
        
        Args:
            amount (float): 量 (mL)
            speed (int): 速度 (1-9)
            
        Returns:
            float: 予想される操作時間 (s)
        """
        estimated_time = nominal_operation_time(amount, speed)
        self.debug_print(f'予想時間: {estimated_time}秒')
        return estimated_time

    async def button(self, button: str, interval: float = 1):
        """
        指定のボタンを押す
        
        Args:
            button (str): 押すボタンの種類（Buttonsクラス定数を使用）
            interval (float, optional): ボタンを押したあとの待機時間(秒). デフォルト: 1
        """
        self._require_connection()
        try:
            self.end_flag = False  # END待ちのフラグをリセット
            await self.send_command(f'{{"button": "{button}"}}')
            # await self.wait_until_END_received() # ENDが受信されるまで待機
            await asyncio.sleep(interval)  # 操作が終わる前にENDが帰ってくる場合があるため一定時間待機
        except ConnectionError:
            raise
        except Exception as e:
            self.debug_print(f"エラー: {e}")

    async def set_motor_mode(self, mode: bool):
        """
        モーターモードを設定する
        
        Args:
            mode (bool): モーターモードを有効にするかどうか
        """
        self._require_connection()
        self.motor_mode = mode
        await self.send_command(
            f'{{"no": 0, "data": "ENABLE_MOTOR_CONTROL {int(mode)}"}}'
        )
        await asyncio.sleep(0.2)
        await self.button(Buttons.TRIGGER_BUTTON_RIGHT)
        await asyncio.sleep(0.2)

    async def aspirate(self, amount: float, speed: int = 5):
        """
        液体を吸引する
        
        Args:
            amount (float): 吸引する量 (mL)。0.5-10mLなど、使用可能な範囲に合わせる
            speed (int, optional): 吸引速度。1-9の範囲。デフォルト: 5
            
        Raises:
            Exception: モーターモードが有効でない場合
        """
        self._require_connection()
        if not self.motor_mode:
            raise Exception("モーターモードを有効にしてください")
        await self.send_command(
            f'{{"no": 0, "data": "RUN_ASPIRATE {amount} {speed}", "gui_pre": "RUN_ASPIRATE"}}'
        )
        # aspirateコマンドを送ってすぐにトリガーを押すと失敗する場合があるため少し待機
        await asyncio.sleep(0.2)
        await self.button(Buttons.TRIGGER_BUTTON_TOP)

        # 操作完了まで待機
        await asyncio.sleep(self.calculate_operation_time(amount, speed))

        # 終了後の待機時間
        await asyncio.sleep(0.2)
        self.debug_print("吸引完了!")

    async def dispense(self, amount: float, speed: int = 5):
        """
        液体を吐出する
        
        Args:
            amount (float): 吐出する量 (mL)。0.5-10mLなど、使用可能な範囲に合わせる
            speed (int, optional): 吐出速度。1-9の範囲。デフォルト: 5
            
        Raises:
            Exception: モーターモードが有効でない場合
        """
        self._require_connection()
        if not self.motor_mode:
            raise Exception("モーターモードを有効にしてください")
        await self.send_command(
            f'{{"no": 0, "data": "RUN_DISPENSE {amount} {speed}", "gui_pre": "RUN_DISPENSE"}}'
        )
        await asyncio.sleep(0.2)
        await self.button(Buttons.TRIGGER_BUTTON_TOP)

        # 操作完了まで待機
        await asyncio.sleep(self.calculate_operation_time(amount, speed))

        # 終了後の待機時間
        await asyncio.sleep(0.2)
        self.debug_print("吐出完了!")

    async def eject_tip(self):
        """
        チップを排出する
        
        Raises:
            Exception: モーターモードが有効でない場合
        """
        self._require_connection()
        if not self.motor_mode:
            raise Exception("モーターモードを有効にしてください")
        await self.send_command(
            f'{{"no": 0, "data": "TIP_EJECT", "gui_pre": "TIP_EJECT"}}'
        )
        await asyncio.sleep(0.2)
        await self.button(Buttons.TRIGGER_BUTTON_TOP)
        
        # 終了待ち
        self.end_flag = False
        await self.wait_until_END_received()

        # 終了後の待機時間
        await asyncio.sleep(0.2)
        self.debug_print("チップ排出完了!")

    async def blow_out(self, go_home: bool = True, speed: int = 1, delay_ms: int = 3000):
        """
        液体をすべて排出する
        
        Args:
            go_home (bool, optional): 終了後にピペット内のピストンがホームポジションに戻るかどうか。デフォルト: True
            speed (int, optional): 排出速度。1-9の範囲。デフォルト: 1
            delay_ms (int, optional): 排出所要時間 (ms)。デフォルト: 3000
            
        Raises:
            Exception: モーターモードが有効でない場合
        """
        self._require_connection()
        if not self.motor_mode:
            raise Exception("モーターモードを有効にしてください")
        await self.send_command(
            f'{{"no": 0, "data": "BLOW_OUT {int(go_home)} {speed} {delay_ms}", "gui_pre": "BLOW_OUT"}}'
        )
        await asyncio.sleep(0.2)
        await self.button(Buttons.TRIGGER_BUTTON_TOP)

        # 操作完了まで待機
        await asyncio.sleep(delay_ms / 1000)

        # 終了後の待機時間
        await asyncio.sleep(0.2)
        self.debug_print("液体排出完了!")

    async def mix(self, cycles: int, speed: int, amount: float):
        """
        液体を混合する
        
        Args:
            cycles (int): 混合サイクル数
            speed (int): 混合速度。1-9の範囲
            amount (float): 混合量 (mL)
            
        Raises:
            Exception: モーターモードが有効でない場合
        """
        self._require_connection()
        if not self.motor_mode:
            raise Exception("モーターモードを有効にしてください")
        await self.send_command(
            f'{{"no": 0, "data": "RUN_MIX {cycles} {speed} {amount}", "gui_pre": "RUN_MIX"}}'
        )
        await asyncio.sleep(0.2)
        await self.button(Buttons.TRIGGER_BUTTON_TOP)

        # 混合操作は途中で停止することがあるため、ENDメッセージを待機
        self.end_flag = False
        await self.wait_until_END_received()

        # 終了後の待機時間
        await asyncio.sleep(0.2)
        self.debug_print("混合完了!")

    def debug_print(self, message: str):
        """
        デバッグメッセージを出力する
        
        Args:
            message (str): 出力するメッセージ
        """
        if self.DEBUG:
            logger.info(message)


async def run_demo():
    """
    Picus2Controllerの接続テスト（USB接続をデフォルトで使用）
    """
    print("=== Picus2 Electronic Pipette Connection Test ===")

    # USB接続の場合（デフォルト）
    port = "COM4"
    connection_type = ConnectionType.USB

    # Bluetooth接続を使う場合はこちらをコメントイン
    # port = "XX:XX:XX:XX:XX:XX"
    # connection_type = ConnectionType.BLUETOOTH

    try:
        print(f"Connecting to Picus2 via {connection_type.value}: {port}")

        # コントローラーの初期化
        picus2 = Picus2Controller(port, connection_type=connection_type)
        picus2.DEBUG = True

        # 接続
        connected = await picus2.connect()

        if connected:
            print("Successfully connected to Picus2!")

            # モーターモード有効化
            print("Enabling motor mode...")
            await picus2.set_motor_mode(True)

            # 簡単な操作テスト
            print("Testing basic operations...")
            await picus2.aspirate(amount=2.0, speed=5)
            await asyncio.sleep(1)
            await picus2.dispense(amount=2.0, speed=5)

            print("Basic operation test completed!")

            # モーターモードから抜ける
            print("Disabling motor mode...")
            await picus2.button(Buttons.TRIGGER_BUTTON_LEFT)
            await picus2.button(Buttons.TRIGGER_BUTTON_RIGHT)

            # 切断
            print("Disconnecting...")
            await picus2.disconnect()
            print("Picus2 test completed successfully!")

        else:
            print("Failed to connect to Picus2")

    except Exception as e:
        print(f"Error occurred: {str(e)}")
        print("Please check:")
        if connection_type == ConnectionType.USB:
            print(f"- Picus2 is connected via USB to {port}")
            print("- COM port is correct (check Device Manager)")
            print("- USB cable is properly connected")
        else:
            print("- Picus2 is powered on and Bluetooth is enabled")
            print(f"- MAC address is correct ({port})")
            print("- Device is not connected to another application")
            print("- Bluetooth adapter is working properly")


if __name__ == "__main__":
    """
    メインエントリーポイント
    """
    # asyncioのイベントループを取得して実行
    loop = asyncio.get_event_loop()
    loop.run_until_complete(run_demo())
    loop.close()

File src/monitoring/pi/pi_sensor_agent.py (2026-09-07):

"""Sensor agent for the Raspberry Pi Zero WH + Waveshare Environment Sensor HAT.

Reads the on-board I2C sensors and pushes a JSON line per sample over TCP to the
control PC running the dashboard (see ``src/monitoring/dashboard/launch_sensor_dashboard.py``).

Sensors read (I2C addresses on the default bus, ``/dev/i2c-1``):

    - BME280   0x76  temperature, humidity
    - TSL25911 0x29  illuminance (lux)
    - ICM20948 0x68  3-axis acceleration, 3-axis angular velocity
    - LTR390   0x53  UV index (UVI)
    - SGP40    0x59  VOC (raw signal, not converted to an index)

Note: the ICM20948 also contains an AK09916 magnetometer accessible through its
auxiliary I2C bus, but this agent does NOT read it. Only the accelerometer and
gyroscope of the ICM20948 are used.

Note on the UV channel: recordings made before 2026-09-08 were taken with the
LTR390 left in ALS mode, in which the UVS data registers never update, so their
``uvi`` column is 0 throughout. From this version the sensor is initialised in
UVS mode and ``uvi`` carries a UV index (float). The CSV column name is
unchanged, so old files stay parseable — only the semantics changed.

Dependencies are kept minimal on purpose (the Pi Zero has limited resources and
this script should run with nothing beyond the Python standard library plus
``smbus``/``smbus2``): no PyYAML, no third-party sensor drivers.

Configuration (environment variables, all optional except the host):

    SENSOR_AGENT_PC_HOST      Required. Hostname or IP address of the control PC.
                               There is no default — an unset value is treated as
                               a configuration error (see below), so a stale
                               address is never silently used.
    SENSOR_AGENT_PC_PORT      TCP port of the dashboard's sensor listener. Default: 50001.
    SENSOR_AGENT_INTERVAL_S   Delay between samples, in seconds. Default: 0.1.

Command-line arguments ``--host``, ``--port`` and ``--interval`` override the
corresponding environment variables. If neither an env var nor ``--host`` is
given, the agent prints an error and exits with status 1 instead of guessing an
address.

Usage:

    SENSOR_AGENT_PC_HOST=192.0.2.10 python3 pi_sensor_agent.py
    python3 pi_sensor_agent.py --host 192.0.2.10 --port 50001

Runs as a systemd service in normal operation; see ``sensor-agent.service`` and
``sensor-agent.env.example`` in this directory.
"""
import argparse
import json
import os
import socket
import struct
import sys
import time

try:
    import smbus
except ImportError:
    try:
        import smbus2 as smbus
    except ImportError:
        print("[!] Error: smbus or smbus2 library not found. Install with: sudo apt install python3-smbus")


class BME280:
    """Bosch BME280 temperature/humidity sensor."""

    def __init__(self, bus, address=0x76):
        self.bus = bus
        self.address = address
        self.calib = []
        self.chip_id = 0
        self.model = "Unknown"
        self.load_calibration()

    def load_calibration(self):
        try:
            # 1. Reset the sensor
            self.bus.write_byte_data(self.address, 0xE0, 0xB6)
            time.sleep(0.1)

            # 2. Check the chip ID
            self.chip_id = self.bus.read_byte_data(self.address, 0xD0)
            if self.chip_id == 0x60: self.model = "BME280 (T/H)"
            elif self.chip_id == 0x58: self.model = "BMP280 (T only)"

            # 3. Read the calibration data
            c1 = self.bus.read_i2c_block_data(self.address, 0x88, 24)
            c2 = [self.bus.read_byte_data(self.address, 0xA1)]
            c3 = self.bus.read_i2c_block_data(self.address, 0xE1, 7)
            self.calib = c1 + c2 + c3
        except: pass

    def read_data(self):
        try:
            if not self.calib: return 0.0, 0.0

            # Write order matters for enabling humidity: 0xF2 must be written before 0xF4
            self.bus.write_byte_data(self.address, 0xF2, 0x01) # Hum x1
            self.bus.write_byte_data(self.address, 0xF4, 0x25) # Temp x1, Press x1, Forced mode

            # Wait for the measurement to finish (up to 50ms)
            for _ in range(10):
                status = self.bus.read_byte_data(self.address, 0xF3)
                if not (status & 0x08): break
                time.sleep(0.01)

            data = self.bus.read_i2c_block_data(self.address, 0xF7, 8)

            # --- Temperature ---
            adc_t = (data[3] << 12) | (data[4] << 4) | (data[5] >> 4)
            dig_T1 = (self.calib[1] << 8) | self.calib[0]
            dig_T2 = struct.unpack("<h", bytes(self.calib[2:4]))[0]
            dig_T3 = struct.unpack("<h", bytes(self.calib[4:6]))[0]

            v1 = ((((adc_t >> 3) - (dig_T1 << 1))) * (dig_T2)) >> 11
            v2 = (((((adc_t >> 4) - (dig_T1)) * ((adc_t >> 4) - (dig_T1))) >> 12) * (dig_T3)) >> 14
            t_fine = v1 + v2
            temp = (t_fine * 5 + 128) >> 8

            # --- Humidity ---
            humi = 0.0
            if self.chip_id == 0x60:
                adc_h = (data[6] << 8) | data[7]
                if adc_h != 0x8000: # 0x8000 means "not measured"
                    dig_H1 = self.calib[24]
                    dig_H2 = struct.unpack("<h", bytes(self.calib[25:27]))[0]
                    dig_H3 = self.calib[27]
                    dig_H4 = (self.calib[28] << 4) | (self.calib[29] & 0x0F)
                    dig_H5 = (self.calib[30] << 4) | (self.calib[29] >> 4)
                    dig_H6 = struct.unpack("<b", bytes([self.calib[31]]))[0]

                    vh = t_fine - 76800
                    vh = (((((adc_h << 14) - (dig_H4 << 20) - (dig_H5 * vh)) + 16384) >> 15) *
                          (((((((vh * dig_H6) >> 10) * (((vh * dig_H3) >> 11) + 32768)) >> 10) + 2097152) * dig_H2 + 8192) >> 14))
                    vh = vh - (((((vh >> 15) * (vh >> 15)) >> 7) * dig_H1) >> 4)
                    vh = 0 if vh < 0 else vh
                    vh = 419430400 if vh > 419430400 else vh
                    humi = vh >> 22
                    humi = humi / 1024.0

            return temp / 100.0, humi
        except:
            return 0.0, 0.0


class TSL25911:
    """AMS TSL25911 ambient light sensor (illuminance)."""

    def __init__(self, bus, address=0x29):
        self.bus = bus; self.address = address
        try: self.bus.write_byte_data(self.address, 0xA0, 0x03)
        except: pass
    def read_lux(self):
        try:
            l, h = self.bus.read_byte_data(self.address, 0xB4), self.bus.read_byte_data(self.address, 0xB5)
            return (h << 8) | l
        except: return 0
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

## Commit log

2026-09-07 Scaffold repository for the automated experimentation platform
    Directory skeleton, licensing structure (MIT code / CC BY 4.0 CAD /
    AGPL-isolated YOLOv8 module), BOM, and documentation placeholders
    accompanying the paper 'Quantitative control and improved reproducibility
    of materials synthesis processes using an automated experimentation
    platform'.
    Claude-Session: https://claude.ai/code/session_015mLoNTU8dRuWeZKSRLS1zC
2026-09-07 Re-port control core from the lab repository and align the public release with the paper
    Control core (src/flow, src/devices) is re-ported from lab_automation_CUI at
    its 2026-07-12 state instead of the older snapshot: ExperimentSession with
    emergency stop on Ctrl+C, ExperimentLogger (run.log / measurements.csv /
    summary.md / metadata.json), dispense-accuracy logger, config.yaml as the
    single source of ports and workspace limits, workspace validator wired into
    the executor, Dobot force_stop/_require_device, and the pytest suite.
    Residual driver bugs fixed on top of that: Picus 2 connection failures now
    raise instead of silently succeeding, the balance parser keeps the sign of
    negative readin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
    [control.example.csv, profiles.csv, sensor_session_sample.csv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]
2026-09-11 Add STL models of the four 3D-printed fixtures
    Binary STL exports from Fusion 360 (robot-arm pedestal, Picus 2 holder,
    balance splash cover, imaging stand). Files renamed to ASCII; meshes checked
    to be closed. F3D/STEP sources are still to be added; cad/README.md,
    README.md and docs/bom.md now say STL is included and the sources follow.
    Claude-Session: https://claude.ai/code/session_011SZzF4bgwcrAG7VCpwy7Hb
    [balance_cover_bce822i.stl, dobot_magician_holder_210mm.stl, imaging_stand_assembly.stl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]
2026-09-11 Add Fusion 360 sources for the fixtures and the imaging light shield
    .f3d for the arm pedestal and pipette holder, .f3z archive for the imaging
    stand assembly, and a new light-shield part (.f3d + .stl). Renamed to ASCII.
    The balance cover still lacks its .f3d.
    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
    [dobot_magician_holder_210mm.f3d, imaging_stand_assembly.f3z, imaging_stand_light_shield.f3d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]
2026-09-12 CI: install zeroconf, needed to import the sensor dashboard in tests
    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
2026-09-13 Pre-publication cleanup: remove device serial numbers, placeholder authors and internal references
    - Redact the two pipette serial numbers left in the provenance script comments.
    - Drop the placeholder "TODO: remaining co-authors" entries from CITATION.cff so
    GitHub's citation widget shows only real authors (TODO kept as a comment).
    - Remove an AI-authorship line from the webcam driver docstring.
    - Reword references to the lab control PC / internal re-measure list as
    "not published yet"; rename the detection README section to "Not included".
    - README: examples/zif8 no longer claims to contain process logs; add the
    dispensing_stability row; CC BY 4.0 link for docs.
    - Fix import paths in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
2026-09-14 Add CLAUDE.md/AGENTS.md guidance for AI coding agents and describe that workflow in the README
    The intended adoption path is to open the repository in an AI coding agent and
    adapt it in conversation. The guidance file gives the agent the repository map,
    the hardware-free verification commands, and the rules it must keep: never start
    a real run on its own, never weaken the safety layer or workspace limits, adapt
    through configuration and flows rather than drivers, keep secrets out of the
    tree, respect the AGPL boundary of detection/, and not invent measurements.
    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
2026-09-14 cad: add the balance-cover Fusion source and two vessel adapters for its opening
    - balance_cover_bce822i.f3d fills the "not yet added" editable source.
    - balance-cover/adapters/: vial_adapter_screw_no4 (ring for a No. 4 screw-cap
    vial, 92 x 92 x 10 mm) and tube_adapter_centrifuge_50ml (sleeve for a 50 mL
    centrifuge tube, 90 x 92 x 70 mm). Both share the same seat in the cover's
    Ø82 mm opening, so they live in one directory with descriptive file names
    instead of one sub-directory each.
    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
    [balance_cover_bce822i.f3d, tube_adapter_centrifuge_50ml.f3d, tube_adapter_centrifuge_50ml.stl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]
2026-09-14 docs: recommend a cheaper IKA plate; the RET control-visc weighing function is not used
    IKA's technical data for the RET control-visc give a weighing range of
    10-5000 g and an accuracy of ±(0.3 % + 2) g, which is far too coarse for
    the few-gram dispenses this platform measures; all masses come from the
    electronic balance. The driver only sends the NAMUR stirring/temperature
    commands, which the IKA Plate (RCT digital) also supports over RS-232/USB at
    about 60 % of the list price. The BOM now says so (and corrects the maximum
    temperature from 400 °C to IKA's 340 °C), setup.md names the alternative,
    and the driver README marks the weighing methods as RET-only and unused.
    Operation with an RC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
2026-09-15 cad: credit the designer of each component
    Add a Designers section (name, affiliation, contact) and a Designer column to
    the component table. The Picus 2 pipette holder was designed by Takaya
    Muramoto; the robot-arm pedestal, balance cover with its adapters and the
    imaging stand by Yusuke Hashimoto.
    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
2026-09-16 docs: add a step-by-step guide to adding an instrument
    docs/adding-an-instrument.md walks through the seven places a new
    instrument touches, using a digital multimeter as the example and the
    balance as the code to copy: driver package, SharedDevices, the mock,
    flow schema and executor, the run-log column, configuration keys, tests
    and documentation. It ends with a checklist and the things not to do
    (bypassing the safety wrapper, lab addresses in defaults, AGPL drivers
    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
